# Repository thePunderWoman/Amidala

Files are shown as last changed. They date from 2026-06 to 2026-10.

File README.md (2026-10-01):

<p align="center">
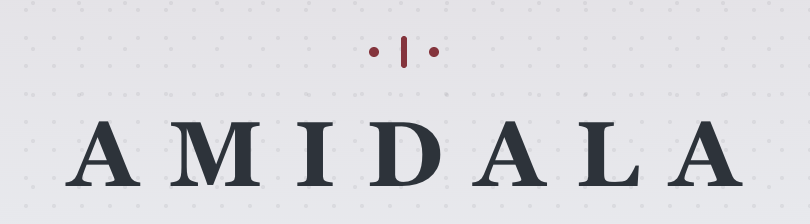
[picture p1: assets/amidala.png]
Amidala
  
</p>

<p align="center">
  <a href="https://github.com/thePunderWoman/Amidala/actions/workflows/ci.yml">
    
  </a>
  <a href="https://github.com/thePunderWoman/Amidala/releases/latest">
    
  </a>
</p>

**Amidala** is an ESP32-S3 firmware for controlling your droids. It runs on the [Amidala PCB](PCB/) — a PCB designed to make wiring a full-featured droid build straightforward — and is compatible with both the N8R2 (8 MB flash) and N16R8 (16 MB flash) module variants. Amidala is designed to pair with [Snips Controllers](https://github.com/thePunderWoman/SnipsControllers), coming soon, but can work with older Stealth controllers, bluetooth, or RC.

> **Building from source?** Flash size and PSRAM mode are baked into the firmware image at build time, so you need to tell PlatformIO which module your board has *before* your first flash — it can't be changed later via the web UI. Check the label on your ESP32-S3 module (or your PCB order) for "N8R2" or "N16R8", then build/upload with the matching environment: `pio run -e esp32s3-n16r8 -t upload` (the default) or `pio run -e esp32s3-n8r2 -t upload`. Just want to flash a droid rather than develop firmware? The **Firmware Installer** wizard below flashes a prebuilt image over USB — no toolchain needed.

> **[Amidala Wizards →](https://thepunderwoman.github.io/Amidala/)** — browser-based tools for setting up your droid. Includes a **Firmware Installer** for flashing prebuilt firmware over Web Serial, and a **Config Converter** for migrating Stealth RC / OG Amidala configs to the current format.

---

## Features

- **XBee wireless control** — secure, long-range, low-latency control via XBee 3 modules
- **Multiple Controller Support** — works with Snips Controllers (currently in prototype stage), classic stealth controllers, standard Bluetooth gamepads, and analog RC (PPM) input.
- **Wi-Fi configuration UI** — browser-based interface for fully configuring your droid without needing to pull the SD card.
- **WCB mesh networking** — join a [WCB](https://github.com/greghulette/WCBClient) ESP-NOW mesh to coordinate commands across multiple boards (e.g. a separate body controller) with no extra wiring.
- **Native HCR support** — full Human Cyborg Relations vocalizer integration, whether the HCR is wired straight to the board or owned by a WCB running its native HCR mode (Audio page → Serial Configuration).
- **Built in Serial Monitor** — full featured onboard native serial monitor to view traffic in real time, even across your WCB Mesh.
- **Advanced Dome Drive** — Built-in support for auto dome drive with a Pololu encoder motor and hall sensor, or any other basic PWM dome drive.
- **Flexible drive systems** — PWM, Sabertooth serial, or RoboteQ (PWM, serial, or hybrid)
- **Native built-in safety features** — Web based e-stop, dome obstruction motor disconnect, auto motor disable on controller disconnect.
- **Layers of controller button configurations** — with short-press, double-press, long-press, and alt-modifier layers
- **Effectively unlimited serial strings and gestures** — the only limits are your imagination!
- **Reassignable GPIO pin roles** — trade any of the board's digital output, analog input, PPM, or servo headers for another role right from the web UI (e.g. give up a digital output for a 5th servo channel), no reflashing needed
- **Reassignable dome/drive serial ports** — move the dome drive or drive system's serial link (RoboClaw, Sabertooth, RoboteQ serial) onto either of the board's two hardware UARTs from the web UI, for wiring that doesn't match the reference PCB or to free up a header for other hardware
- **And more** — I2C aux output, digital outputs, analog inputs, SD card config, servo outputs, and emergency stop handling

---

## Controller Support

Amidala is natively designed to work with [Snips Controllers](https://github.com/thePunderWoman/SnipsControllers) or other XBee-based dual handheld pocket controllers. It can also be used with standard Bluetooth controllers and RC.

## Web Configuration UI

<p align="center">
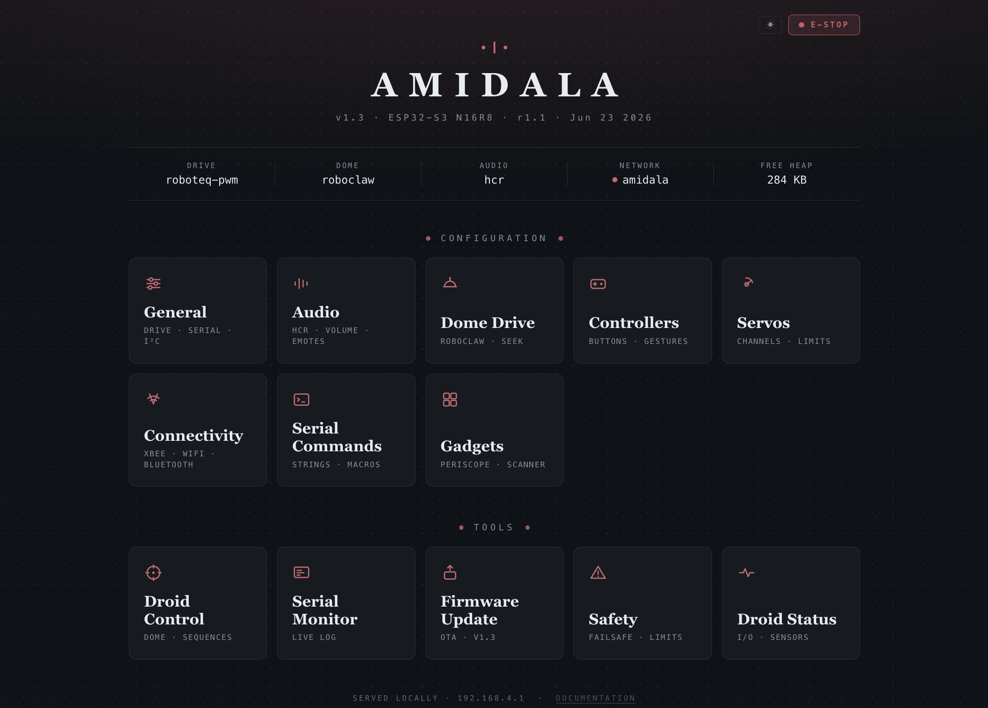
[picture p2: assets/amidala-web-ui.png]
Amidala
  
</p>

The Amidala web interface allows you total control over your droid's configuration. You can set up your controller configuration, which buttons trigger what, add serial commands, set defaults for audio, dome positioning, safety timeouts, emergency stop commands, configure Bluetooth, see digital pin statuses, use the serial monitor, configure your droid's gadgets, and even use the droid control page to trigger sequences, trigger emotes, and dome controls. See more in the wiki.

## Availability and Pricing

Amidala boards are currently available to beta testers. Please let me know if you would prefer to have it pre-soldered or bare. Either way, it will come with the headers, slots, jumper, and power terminals. The ESP32-S3-N16R8 is standard and can be sourced from your favorite location. You will also need an XBee3 module if you intend to use Snips or Stealth controllers with your build. See the Wiki page for details on the recommended options. Price is $30 per board plus shipping, which includes a small donation to charity. Note: This does __not__ include controllers. However, once Snips Controllers are past the prototype phase, we will offer them together with Amidala.

Please reach out if you are interested in helping beta test.

## Get Started

> **[Documentation Wiki →](https://github.com/thePunderWoman/Amidala/wiki)**

The wiki covers everything from first flash through full configuration. For a quick look at every available config key, see [example_config.txt](example_config.txt) — it's a complete annotated reference used on a real build. Although once you get set up initially, you won't need to look at this file again, as you can update every config option through the web UI.

---

## The Amidala PCB

<p align="center">
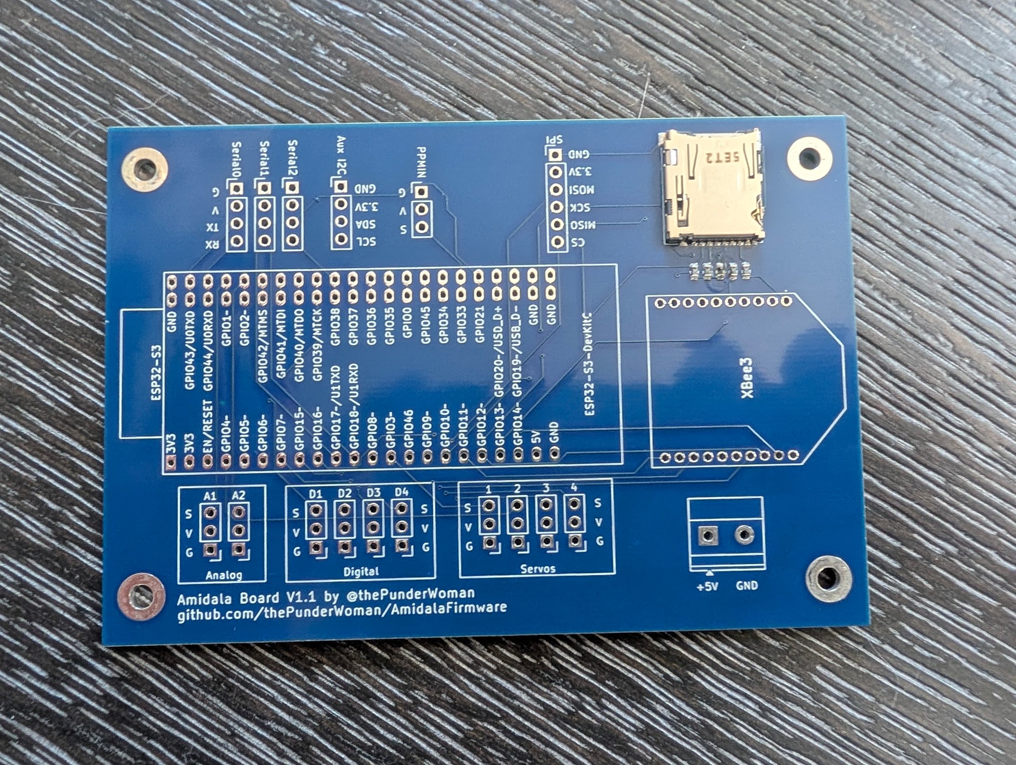
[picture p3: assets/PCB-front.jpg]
Amidala PCB front
  
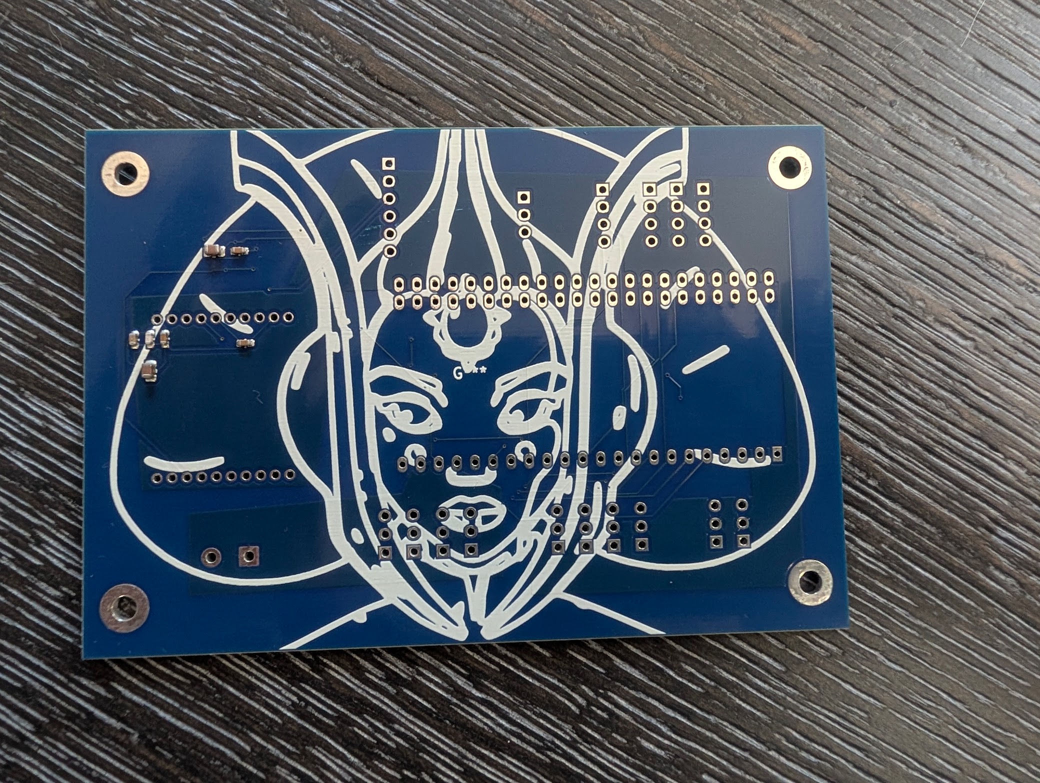
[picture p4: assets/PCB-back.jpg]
Amidala PCB back
  
</p>

The Amidala PCB is a purpose-built carrier for the ESP32-S3, designed to consolidate all the connectors a typical R2 build needs onto a single board:

- 4 servo headers (LEDC PWM)
- 4 digital output pins
- 2 analog inputs
- 3 serial headers (UART0 primary out, plus UART1 and UART2 for the dome drive and drive system's serial link — reassignable between the two, see below)
- Auxiliary I2C header
- Native XBee slot (SPI, no adapter needed)
- Micro SD card reader
- Additional SPI breakout
- PPM input for RC receivers

> The servo, digital output, analog input, and PPM header counts above are just the defaults — each of those 11 pins can be independently reassigned to a different role from the web UI's Pins page (e.g. trade a digital output for a 5th servo channel, up to the ESP32-S3's 8-channel PWM ceiling). A reboot applies the change; no reflashing or rewiring of the PCB itself is needed.
>
> Likewise, UART1 and UART2 default to the dome drive and drive system's serial link respectively (matching the reference wiring), but either can be reassigned to the other from the web UI's Serial Ports page — e.g. if your build's wiring swaps which header the RoboClaw is actually connected to. UART0 always carries the primary serial-out / WCB mesh path and isn't reassignable.

> **[PCB details, Stackup circuit design, and BOM →](PCB/)**

---

## License

This project is released under the [GNU General Public License v2](LICENSE). You are free to use, modify, and distribute it — including your own modifications — as long as you share the source code of any distributed derivatives under the same license.

---

## Contributing

Bug reports and feature requests are welcome — please use the [issue tracker](https://github.com/thePunderWoman/Amidala/issues).

If you'd like to contribute code, see [CONTRIBUTING.md](CONTRIBUTING.md).

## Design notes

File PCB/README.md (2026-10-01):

# AmidalaBoard (AmidalaShield)

A custom KiCad PCB shield designed specifically for the [Amidala Firmware](https://github.com/thePunderWoman/AmidalaFirmware) — a control system for astromech and similar droid builds. This board provides all the I/O the firmware needs in a single, purpose-built package.

**Designed by [thePunderWoman](https://github.com/thePunderWoman)**

The electrical design is written in [Stackup KDL](stackup/board.kdl), using the pinned
Stackup parts library plus [board-specific parts](stackup/parts.kdl). The
[KiCad PCB](AmidalaShield.kicad_pcb) is linked to it through `AmidalaShield.stackup_sch`;
sync it with the Stackup KiCad plugin after changing the design. See
[stackup/README.md](stackup/README.md).

---

## Overview

The AmidalaShield is a carrier/breakout board for the **ESP32-S3 N16R8 DevKit**. It breaks out and conditions the ESP32-S3's peripherals for the specific needs of the Amidala Firmware: wireless XBee communication, multi-channel servo control, RC receiver input, SD card storage, and expansion headers for additional peripherals.

---

## Requirements

- **Microcontroller:** ESP32-S3 N16R8 DevKit (16 MB flash, 8 MB PSRAM)
- **Wireless modules:** XBee3 modules (x2 recommended — one for drive controller, one for dome controller)

---

## Hardware Features

### Wireless Communication
- **XBee3 module socket** for dual-controller operation (drive + dome)

### Servo Control
- **4× PWM servo outputs** — 3-pin headers (signal, power, ground)

### Serial Ports
- **3× hardware serial ports** — UART0 (shared with USB/programming, silkscreen "Serial 0"), UART1 ("Serial 1"), and UART2 ("Serial 2"). None of these are bit-banged/software serial — the ESP32-S3's UART peripherals route through its GPIO matrix onto whichever pins are needed, unlike chips with a single hardware UART. Firmware reassigns the dome drive and drive system's serial link between Serial 1/Serial 2 at runtime — see the Amidala firmware wiki's [Serial Ports](https://github.com/thePunderWoman/Amidala/wiki/Serial-Ports) page.

### I/O
- **4× digital I/O pins**
- **2× analog input pins**
- **1× Aux I2C header** — for external I2C devices

### RC Control
- **PPM input (ppmin)** — for analog RC receiver

### Storage
- **Built-in microSD card reader** — used for `config.txt` at startup (matches Amidala Firmware config system)

### Expansion
- **Dedicated SPI header** — for external SPI peripherals

---

## Repository Contents

| File/Folder | Description |
|---|---|
| `stackup/board.kdl` | Electrical design (Stackup KDL), replacing the KiCad schematics |
| `stackup/parts.kdl` | Parts the Stackup library doesn't have (DevKitC, microSD socket, screw terminal, 3-way jumper) |
| `AmidalaShield.kicad_pcb` | PCB layout, synced from the Stackup design |
| `gerbers/` | Production-ready Gerber files |
| `libraries/` | Project-specific KiCad symbol/footprint libraries |
| `images/` | Board renders and screenshots |

---

## Getting Started

1. Clone this repo and open `AmidalaShield.kicad_pro` in KiCad 8+.
2. Review the [Stackup design](stackup/board.kdl) and the GPIO table below for pin assignments before assembling.
3. Use the Gerber files in `gerbers/` to order PCBs from your preferred fab.
4. Flash your ESP32-S3 with the [Amidala Firmware](https://github.com/thePunderWoman/AmidalaFirmware).
5. Place a `config.txt` on the microSD card — see the firmware repo for a full annotated example.

---

## GPIO Table

> **V1.1** — Updated GPIO assignments for ESP32-S3 WROOM-1 N8R2/N16R2 (Quad flash/PSRAM).
> Avoid GPIO35–37 on R8 (Octal) variants. GPIO48 reserved for onboard RGB LED.

| Function | GPIO | DevKit Side | Notes |
|---|---|---|---|
| **SPI MOSI** | GPIO11 | Left | Native FSPI, shared bus |
| **SPI MISO** | GPIO13 | Left | Native FSPI, shared bus |
| **SPI SCK** | GPIO12 | Left | Native FSPI, shared bus |
| **SD Card CS** | GPIO10 | Left | |
| **XBee CS** | GPIO7 | Left | |
| **SPI Spare CS** | GPIO14 | Left | Exposed header |
| **XBee ATTN** | GPIO16 | Left | |
| **XBee SLEEP** | GPIO15 | Left | |
| **I2C SDA** | GPIO8 | Left | Native I2C default |
| **I2C SCL** | GPIO9 | Left | Native I2C default |
| **UART0 TX** | GPIO43 | Right | Shared w/ USB — do not use simultaneously. Silkscreen "Serial 0"; fixed, carries the main serial-out/WCB mesh path |
| **UART0 RX** | GPIO44 | Right | Shared w/ USB — do not use simultaneously |
| **UART1 TX** | GPIO17 | Right | Silkscreen "Serial 1". Reassignable between the dome/drive serial link (default: dome) |
| **UART1 RX** | GPIO18 | Right | |
| **UART2 TX** | GPIO21 | Right | Silkscreen "Serial 2". Real hardware UART, not software serial. Reassignable between the dome/drive serial link (default: drive) |
| **UART2 RX** | GPIO38 | Right | |
| **PPMIN** | GPIO47 | Right | |
| **Analog 1** | GPIO1 | Right | ADC1_0, WiFi-safe |
| **Analog 2** | GPIO2 | Right | ADC1_1, WiFi-safe |
| **Servo 1** | GPIO3 | Left | Strapping pin (JTAG source), safe after boot |
| **Servo 2** | GPIO4 | Left | |
| **Servo 3** | GPIO5 | Left | |
| **Servo 4** | GPIO6 | Left | |
| **Digital 1** | GPIO39 | Right | Goes HIGH after reset (not LOW like most GPIOs) |
| **Digital 2** | GPIO40 | Right | |
| **Digital 3** | GPIO41 | Right | |
| **Digital 4** | GPIO42 | Right | Transitions low on reset slightly slower |
| **RGB LED** | GPIO48 | Right | Reserved — onboard DevKit RGB LED |
| **NC** | GPIO8 | Left | Reserved |

### Pins Intentionally Avoided

| GPIO | Reason |
|---|---|
| GPIO0 | Strapping pin — boot mode |
| GPIO3 | Strapping pin — JTAG source (used for Servo 1, safe after boot) |
| GPIO19/20 | USB D-/D+ |
| GPIO26–32 | Internal SPI flash/PSRAM — never use |
| GPIO35–37 | Internal on Octal (R8) variants — safe on R2 only |
| GPIO45 | Strapping pin — VDD_SPI voltage |
| GPIO46 | Strapping pin |

---

## License

This hardware design is licensed under the [Creative Commons Attribution-NonCommercial-ShareAlike 4.0 International License](LICENSE.md) (CC BY-NC-SA 4.0).

You are free to share and adapt this design for non-commercial purposes, as long as you give appropriate credit and distribute any adaptations under the same license.

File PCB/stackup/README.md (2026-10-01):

# Amidala Shield Stackup design

`board.kdl` is the shield's electrical design. It imports parts from the
[Stackup library](https://github.com/stackup-eda/library) pinned in the repository's
`manifest.kdl`. `parts.kdl` defines the parts the library doesn't have: the ESP32-S3-DevKitC-1,
the Hirose microSD socket, the 5 V screw terminal and the 3-way supply jumper.

The design was ported 1:1 from the KiCad schematics. Designators and net names are unchanged, so
the existing routing in `../AmidalaShield.kicad_pcb` carried over as-is.

From the repository root:

```sh
stackup check PCB/stackup/board.kdl --locked     # check the design
```

To update the PCB after changing the design, use **Sync PCB from stackup** in KiCad's PCB editor
(the board is linked by `PCB/AmidalaShield.stackup_sch`), or sync it headless with the board
closed:

```sh
/Applications/KiCad/KiCad.app/Contents/Frameworks/Python.framework/Versions/Current/bin/python3 \
  <stackup checkout>/kicad-plugin/sync_headless.py PCB/AmidalaShield.kicad_pcb
```

Commit the synced PCB together with the KDL change. CI checks the design with the Cargo-locked CLI
in `ci/stackup/` and fails if syncing would change the committed PCB. Each footprint records the
`board.kdl` line it came from, so even a change that only moves lines needs a resync.

Install the same CLI version CI uses with `cargo install stackup-eda --version 0.2.0 --locked`, and
the KiCad plugin from a checkout of [stackup-eda/stackup](https://github.com/stackup-eda/stackup)
at `v0.2.0` with `python3 kicad-plugin/install.py`.

## Known gaps carried over from the schematics

- **No MPNs.** The original schematics didn't specify purchasing details, so `stackup bom` reports
  every part as missing an MPN.
- **XBee3 SPI_ATTN has no pull-up.** `stackup check` reports a note that the strap's rest level
  can't be checked. The fix is a resistor in the next board revision (issue #185).

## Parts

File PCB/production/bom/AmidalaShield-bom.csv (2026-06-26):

Id | Designator | Footprint | Quantity | Designation | Supplier and ref
1 | R3,R1,R2,R5 | R_0603_1608Metric | 4 | 10k
2 | C4,C7 | C_0805_2012Metric | 2 | 10u
3 | C2,C1,C3 | C_0603_1608Metric | 3 | 100n
4 | C9 | CP_EIA-3216-18_Kemet-A | 1 | 100µF
5 | J3 | microSD_HC_Hirose_DM3AT-SF-PEJM5 | 1 | Micro_SD_Card
6 | C6 | C_0603_1608Metric | 1 | 8.2p
7 | C5 | C_0603_1608Metric | 1 | 1u

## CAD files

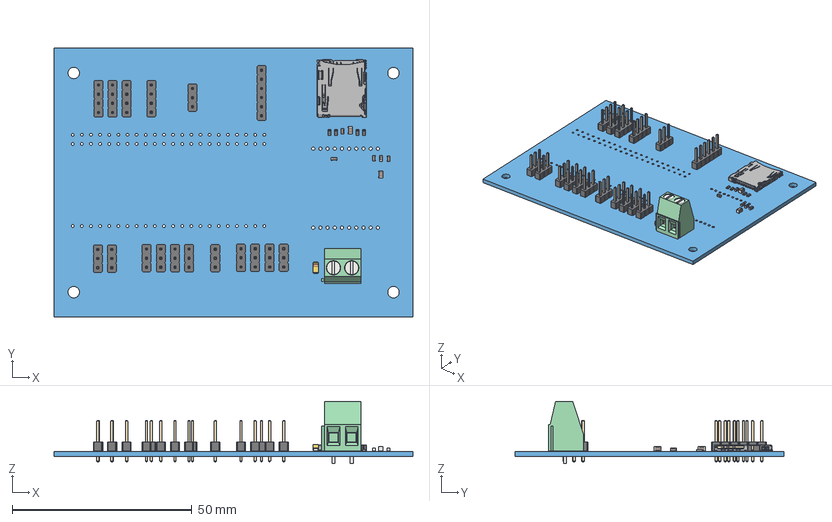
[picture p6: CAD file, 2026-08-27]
PCB/AmidalaShield.step
99.9 x 74.9 x 17.3 mm
R_0603_1608Metric x 4
PinHeader_1x04_P2.54mm_Vertical x 4
C_0805_2012Metric x 2
C_0603_1608Metric x 5
PinHeader_1x03_P2.54mm_Vertical x 12
TerminalBlock_Phoenix_MKDS-1,5-2-5.08_1x02_P5.08mm_Horizontal
CP_EIA-3216-18_Kemet-A
PinHeader_1x06_P2.54mm_Vertical
microSD_HC_Hirose_DM3AT-SF-PEJM5
AmidalaShield_PCB

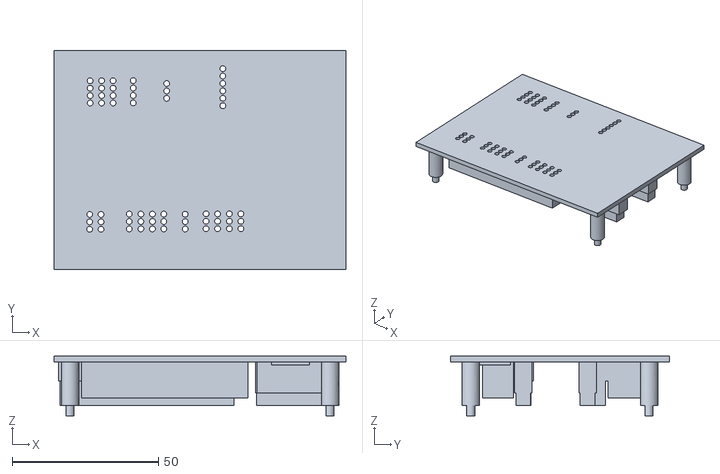
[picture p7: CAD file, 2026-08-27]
PCB/amidala solder jig.stl
99.9 x 74.9 x 20.5

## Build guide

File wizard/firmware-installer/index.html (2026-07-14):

# Amidala Firmware Installer

Build a firmware image for your exact hardware and flash it over USB — no toolchain required.

Checking latest release…

1

Select Hardware

2

Connect & Flash

3

Done

## Tell us about your build

These are compile-time hardware choices — pick the ones that match your droid. Everything else (WiFi, audio, buttons, gestures) is configured later through the web UI.

ESP32-S3 module

Check the label on your ESP32-S3 module (or your PCB order) for "N8R2" or "N16R8" — this can't be changed later without reflashing.

Drive system

Whichever motor controller drives your legs.

Dome drive

Whichever motor controller spins your dome.

Continue →

## Enter bootloader mode

The ESP32-S3's USB port has no auto-reset circuitry, so you'll need to put it into bootloader mode by hand before connecting:

1. Plug the board in over USB, if it isn't already.
2. Hold the BOOT button.
3. Tap and release RESET (while still holding BOOT).
4. Release BOOT.
5. Click Connect below and select the board's serial port.

⚠ Before you flash This installs fresh firmware and erases all saved settings on the board (WiFi credentials, config, calibration) — this is meant for first-time setup or a full reset, not an incremental update. Do not disconnect the board once flashing starts.

Connect Flash Firmware

Preparing…

0%

Log

← Back

✓ Flash complete — your board is rebooting into the new firmware.

## Next steps

Once the board reboots, it broadcasts its own WiFi access point — connect to it and open the web UI to finish setup (WiFi, audio, buttons, gestures, and more).

Migrating an existing Stealth RC or OG Amidala config? Use the Config Converter to bring your old settings forward.

Flash Another Board

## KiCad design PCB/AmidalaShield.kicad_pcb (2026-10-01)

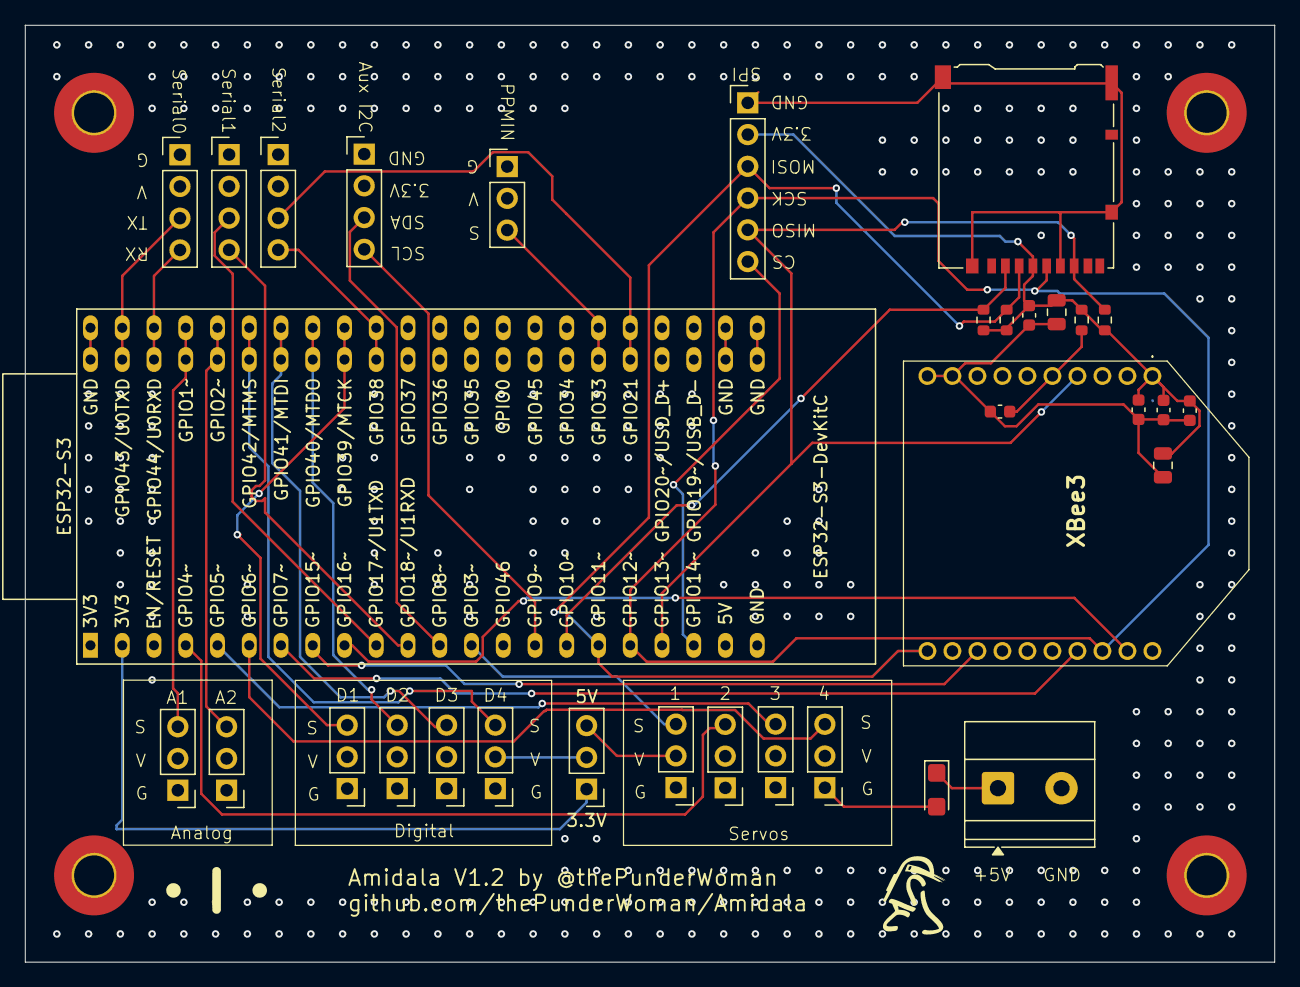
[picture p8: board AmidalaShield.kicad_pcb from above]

Board: 4 copper layers, 99.9 x 74.9 mm, 33 parts (0 on the bottom side), 32 nets.

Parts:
C1, C2, C3: 100nF; C_0603_1608Metric
C4, C7: 10µF; C_0805_2012Metric
C5: 1µF; C_0603_1608Metric
C6: 8.2pF; C_0603_1608Metric
C9: 100µF; CP_EIA-3216-18_Kemet-A
ESP32-S3: ESP32-S3-DevKitC; ESP32-S2-DevKitC-1
I2C1: Aux I2C; PinHeader_1x04_P2.54mm_Vertical
J1: Screw_Terminal_01x02; TerminalBlock_Phoenix_MKDS-1,5-2-5.08_1x02_P5.08mm_Horizont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
J3: Micro_SD_Card; microSD_HC_Hirose_DM3AT-SF-PEJM5
JP1: Jumper_3_Open; PinHeader_1x03_P2.54mm_Vertical
J_Analog1: A1; PinHeader_1x03_P2.54mm_Vertical
J_Analog2: A2; PinHeader_1x03_P2.54mm_Vertical
J_Digital1: D1; PinHeader_1x03_P2.54mm_Vertical
J_Digital2: D2; PinHeader_1x03_P2.54mm_Vertical
J_Digital3: D3; PinHeader_1x03_P2.54mm_Vertical
J_Digital4: D4; PinHeader_1x03_P2.54mm_Vertical
J_PPMIN1: PPMIN; PinHeader_1x03_P2.54mm_Vertical
J_Servo1: 1; PinHeader_1x03_P2.54mm_Vertical
J_Servo2: 2; PinHeader_1x03_P2.54mm_Vertical
J_Servo3: 3; PinHeader_1x03_P2.54mm_Vertical
J_Servo4: 4; PinHeader_1x03_P2.54mm_Vertical
R1, R2, R3, R5: 10kΩ; R_0603_1608Metric
SPI1: SPI; PinHeader_1x06_P2.54mm_Vertical
SWSerial1: Serial2; PinHeader_1x04_P2.54mm_Vertical
Serial0: Serial0; PinHeader_1x04_P2.54mm_Vertical
Serial1: Serial1; PinHeader_1x04_P2.54mm_Vertical
XBee3: XB3-24Z8UT-J; XB324Z8UTJ

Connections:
+3.3V: C2.1, C3.1, C4.1, C5.1, C6.1, C7.1, ESP32-S3.1 (3V3), ESP32-S3.2 (3V3), I2C1.2, J3.4 (VDD), JP1.1 (A), J_PPMIN1.2, R1.1, R2.1, R3.1, R5.1, SPI1.2, SWSerial1.2, Serial0.2, Serial1.2, XBee3.1 (VCC)
+5V: C9.1, ESP32-S3.21 (5V), J1.1, JP1.3 (B), J_Servo1.2, J_Servo2.2, J_Servo3.2, J_Servo4.2
/Comms/GPIO8: ESP32-S3.12 (GPIO8/ADC1_CH7), I2C1.3
/Comms/GPIO9: ESP32-S3.15 (GPIO9/ADC1_CH8), I2C1.4
/Comms/GPIO17: ESP32-S3.10 (GPIO17/ADC2_CH6), Serial1.3
/Comms/GPIO18: ESP32-S3.11 (GPIO18/ADC2_CH7), Serial1.4
/Comms/GPIO21: ESP32-S3.27 (GPIO21), SWSerial1.3
/Comms/GPIO38: ESP32-S3.35 (GPIO38), SWSerial1.4
/Comms/GPIO43: ESP32-S3.43 (GPIO43/U0TXD), Serial0.3
/Comms/GPIO44: ESP32-S3.42 (GPIO44/U0RXD), Serial0.4
/Pins/GPIO1: ESP32-S3.41 (GPIO1/ADC1_CH0), J_Analog1.3
/Pins/GPIO2: ESP32-S3.40 (GPIO2/ADC1_CH1), J_Analog2.3
/Pins/GPIO39: ESP32-S3.36 (GPIO39/MTCK), J_Digital1.3
/Pins/GPIO40: ESP32-S3.37 (GPIO40/MTDO), J_Digital2.3
/Pins/GPIO41: ESP32-S3.38 (GPIO41/MTDI), J_Digital3.3
/Pins/GPIO42: ESP32-S3.39 (GPIO42/MTMS), J_Digital4.3
/RC Control/GPIO47: ESP32-S3.28 (GPIO47), J_PPMIN1.3
/SPI/GPIO7: ESP32-S3.7 (GPIO7/ADC1_CH6), XBee3.17 (AD3/DIO3/SPI_~SSEL)
/SPI/GPIO10: ESP32-S3.16 (GPIO10/ADC1_CH9), J3.2 (DAT3/CD), R2.2
/SPI/GPIO11: ESP32-S3.17 (GPIO11/ADC2_CH0), J3.3 (CMD), R3.2, SPI1.3, XBee3.11 (DIO4/SPI_MOSI)
/SPI/GPIO12: ESP32-S3.18 (GPIO12/ADC2_CH1), J3.5 (CLK), SPI1.4, XBee3.18 (AD2/DIO2/SPI_CLK)
/SPI/GPIO13: ESP32-S3.19 (GPIO13/ADC2_CH2), J3.7 (DAT0), R5.2, SPI1.5, XBee3.4 (DIO12/SPI_MISO)
/SPI/GPIO14: ESP32-S3.20 (GPIO14/ADC2_CH3), SPI1.6
/SPI/GPIO15: ESP32-S3.8 (GPIO15/ADC2_CH4/32K_P), XBee3.13 (ON/~SLEEP/DIO9)
/SPI/GPIO16: ESP32-S3.9 (GPIO16/ADC2_CH5/32K_N), XBee3.19 (AD1/DIO1/SPI_~ATTN)
/Servos/GPIO3: ESP32-S3.13 (GPIO3/ADC1_CH2), J_Servo1.3
/Servos/GPIO4: ESP32-S3.4 (GPIO4/ADC1_CH3), J_Servo2.3
/Servos/GPIO5: ESP32-S3.5 (GPIO5/ADC1_CH4), J_Servo3.3
/Servos/GPIO6: ESP32-S3.6 (GPIO6/ADC1_CH5), J_Servo4.3
GND: C1.2, C2.2, C3.2, C4.2, C5.2, C6.2, C7.2, C9.2, ESP32-S3.22 (GND), ESP32-S3.23 (GND), ESP32-S3.24 (GND), ESP32-S3.44 (GND), I2C1.1, J1.2, J3.6 (VSS), J3.11 (SHIELD), J_Analog1.1, J_Analog2.1, J_Digital1.1, J_Digital2.1, J_Digital3.1, J_Digital4.1, J_PPMIN1.1, J_Servo1.1, J_Servo2.1, J_Servo3.1, J_Servo4.1, SPI1.1, SWSerial1.1, Serial0.1, Serial1.1, XBee3.9 (~DTR/SLEEP_RQ/DIO8), XBee3.10 (GND)
unnamed: C1.1, R1.2, XBee3.5 (~RESET)
VCC_DIG: JP1.2 (C), J_Analog1.2, J_Analog2.2, J_Digital1.2, J_Digital2.2, J_Digital3.2, J_Digital4.2

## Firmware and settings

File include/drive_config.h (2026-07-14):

// drive_config.h
// Drive and dome system configuration for Amidala Firmware.
//
// Edit the two "Active selection" lines to switch hardware configurations.
// Everything below the "Drive system resolution" comment is derived
// automatically — do not edit those lines.

#pragma once

// ---- Drive system type constants --------------------------------------------

#define DRIVE_SYSTEM_PWM                1
#define DRIVE_SYSTEM_SABER              2
#define DRIVE_SYSTEM_ROBOTEQ_PWM        3
#define DRIVE_SYSTEM_ROBOTEQ_SERIAL     4
#define DRIVE_SYSTEM_ROBOTEQ_PWM_SERIAL 5

// Active selection (uncomment the one in use). Guarded by #ifndef so a build
// can also override it via `-D DRIVE_SYSTEM=<n>` (used by the firmware
// installer wizard's CI matrix build) without editing this file.
// #define DRIVE_SYSTEM DRIVE_SYSTEM_ROBOTEQ_PWM_SERIAL
#ifndef DRIVE_SYSTEM
#define DRIVE_SYSTEM DRIVE_SYSTEM_ROBOTEQ_PWM
#endif

// ---- Dome drive type constants -----------------------------------------------

#define DOME_DRIVE_SABER    2
#define DOME_DRIVE_PWM      3
#define DOME_DRIVE_ROBOCLAW 4

// Active selection (uncomment the one in use). Guarded by #ifndef so a build
// can also override it via `-D DOME_DRIVE=<n>` (used by the firmware
// installer wizard's CI matrix build) without editing this file.
// #define DOME_DRIVE DOME_DRIVE_PWM
// #define DOME_DRIVE DOME_DRIVE_SABER
#ifndef DOME_DRIVE
#define DOME_DRIVE DOME_DRIVE_ROBOCLAW
#endif

// ---- Speed and acceleration parameters --------------------------------------

#define MAXIMUM_SPEED       1.0f  // percentage 0.0 - 1.0. default 50%
#define MAXIMUM_GUEST_SPEED 0.5f  // percentage 0.0 - 1.0. default 30%
#define DOME_MAXIMUM_SPEED  1.0f  // percentage 0.0 - 1.0. default 100%

// Scale value of 1 means instant. Scale value of 100 means that the throttle
// will increase 1/100 every 25ms
#define ACCELERATION_SCALE 100
// Scale value of 1 means instant. Scale value of 20 means that the throttle
// will decrease 1/20 every 25ms
#define DECELRATION_SCALE  20

// Set to true if acceleration/deceleration should be applied
#define SCALING false

// ---- Dome motion defaults ---------------------------------------------------

#define DEFAULT_DOME_HOME_POSITION      50
#define DEFAULT_DOME_ACCELERATION_SCALE 20
#define DEFAULT_DOME_DECELERATION_SCALE 50
#define DEFAULT_DOME_SEEK_MIN_DELAY     6
#define DEFAULT_DOME_SEEK_MAX_DELAY     8
#define DEFAULT_DOME_TARGET_MIN_DELAY   0
#define DEFAULT_DOME_TARGET_MAX_DELAY   1
#define DEFAULT_DOME_SEEK_LEFT          80
#define DEFAULT_DOME_SEEK_RIGHT         80
#define DEFAULT_DOME_FUDGE              10
#define DEFAULT_DOME_SPEED_HOME         40
#define DEFAULT_DOME_SPEED_SEEK         60
#define DEFAULT_DOME_SPEED_TARGET       100
#define DEFAULT_DOME_SPEED_MIN          5
#define DEFAULT_DOME_DECEL_ZONE         30
#define DEFAULT_DOME_TIMEOUT            5
#define DEFAULT_DOME_INVERTED           true
#define DEFAULT_DOME_MIN_PULSE          1000
#define DEFAULT_DOME_MAX_PULSE          2000

// ---- RoboClaw dome drive defaults -------------------------------------------
// These apply only when DOME_DRIVE == DOME_DRIVE_ROBOCLAW.

// Serial port used by the RoboClaw.
// UART1 (GPIO17/18) — Serial0 (UART0) carries the WCB downstream output.
// DOME_DRIVE_SERIAL is intentionally NOT defined here so pin_config.h still
// assigns SERIAL = Serial0 for the primary output.
#if DOME_DRIVE == DOME_DRIVE_ROBOCLAW
#define ROBOCLAW_SERIAL    Serial1   // UART1, GPIO17/18
#define ROBOCLAW_RX_PIN    18        // UART1 RX
#define ROBOCLAW_TX_PIN    17        // UART1 TX
#define ROBOCLAW_BAUD_RATE 38400
#endif

// Default RoboClaw hardware settings
#define DEFAULT_DOME_ROBOCLAW_ADDRESS 128  // packet-serial default address (0x80)
#define DEFAULT_DOME_ROBOCLAW_CHANNEL 1    // motor channel: 1 = M1, 2 = M2

// Encoder counts per motor shaft revolution (CPR).
// For the Pololu motor in this build the CPR is 1200.
// Change this constant if a different motor is swapped in; it is not a
// runtime config key because it is a hardware property of the motor itself.
#define DOME_MOTOR_CPR 1200

// Max encoder pulses per second sent to RoboClaw SpeedM1/M2.
// Tune this to the motor's realistic no-load maximum before applying load.
#define DEFAULT_DOME_ROBOCLAW_QPPS 800

// Milliseconds of zero encoder movement while the motor is commanded before
// the system declares an obstruction and stops.
#define DEFAULT_DOME_STALL_TIMEOUT_MS 500

// Milliseconds allowed for the homing sweep to find the hall sensor.
// If it expires the system falls back to manual mode with a console warning.
#define DEFAULT_DOME_HOMING_TIMEOUT_MS 15000

// Speed (fraction of QPPS) used during automatic homing and calibration.
// Keep these low enough to be safe on first power-on.
#define DEFAULT_DOME_HOMING_SPEED   0.20f  // 20 % of QPPS
#define DEFAULT_DOME_CALIBRATE_SPEED 0.30f // 30 % of QPPS

// Hardware debounce window for the hall-effect sensor interrupt (ms).
// Triggers arriving faster than this are ignored.
#define DEFAULT_DOME_HALL_DEBOUNCE_MS 50

// Number of complete dome revolutions averaged during calibration.
#define DOME_CALIBRATION_ROTATIONS 10

// Sequence-pause watchdog (dome=seqon[,<seconds>]).  If no dome=seqoff arrives
// within the pause window, the pause auto-clears so the dome resumes its
// normal auto-behaviors even if the body/dome controller crashes mid-sequence.
#define DEFAULT_DOME_SEQUENCE_PAUSE_MS 30000   // 30s default when no arg given
#define DOME_SEQUENCE_PAUSE_MAX_MS     300000  // 5 min safety cap

// EEPROM layout for RoboClaw calibration data.
// Stored at a fixed offset well past the existing SC23 XBee block (0x64)
// and servo block (0xEA) to avoid collisions.
//
//   Offset  Size  Contents
//   0x200   4     Signature bytes: 'R','C','0','1'
//   0x204   4     int32_t  ticksPerDomeRev  (0 → not yet calibrated)
//
// Reading: if the 4-byte signature matches, load ticksPerDomeRev.
// Writing: always write both signature and data atomically.
#define DOME_ROBOCLAW_EEPROM_ADDR 0x200
#define DOME_ROBOCLAW_EEPROM_SIG0 'R'
#define DOME_ROBOCLAW_EEPROM_SIG1 'C'
#define DOME_ROBOCLAW_EEPROM_SIG2 '0'
#define DOME_ROBOCLAW_EEPROM_SIG3 '1'

// ---- Drive system resolution (derived — do not edit) ------------------------

// Drive/dome serial links use AUX_SERIAL (UART2, GPIO21/38 — see
// pin_config.h) rather than Serial0, which is reserved for the WCB
// downstream output.
#if DRIVE_SYSTEM == DRIVE_SYSTEM_SABER
#define DRIVE_SERIAL      AUX_SERIAL
#define DRIVE_BAUD_RATE   9600      // Sabertooth packet-serial default
// Do NOT also define DOME_DRIVE_SERIAL here: AmidalaFirmware.ino's
// Serial0.begin() already prefers DRIVE_SERIAL over DOME_DRIVE_SERIAL, so
// this was never needed for that call — and defining it unconditionally
// (regardless of DOME_DRIVE) leaked into pin_config.h's
// `#if !defined(DOME_DRIVE_SERIAL)` guard, silently disabling the SERIAL
// macro (WCB downstream output) for any Sabertooth-drive build with a
// non-Sabertooth dome. The block below already sets DOME_DRIVE_SERIAL
// correctly when the dome itself is Sabertooth.
#define CHANNEL_MIXING    true  // premix channels before sending commands
#elif DRIVE_SYSTEM == DRIVE_SYSTEM_PWM
#define CHANNEL_MIXING    false // motor controller will mix the channels
#elif DRIVE_SYSTEM == DRIVE_SYSTEM_ROBOTEQ_PWM
#define CHANNEL_MIXING    false // motor controller will mix the channels
#elif DRIVE_SYSTEM == DRIVE_SYSTEM_ROBOTEQ_SERIAL
#define DRIVE_SERIAL      AUX_SERIAL
#define DRIVE_BAUD_RATE   115200
#define CHANNEL_MIXING    false // motor controller will mix the channels
#elif DRIVE_SYSTEM == DRIVE_SYSTEM_ROBOTEQ_PWM_SERIAL
#define DRIVE_SERIAL      AUX_SERIAL
#define DRIVE_BAUD_RATE   115200
#define CHANNEL_MIXING    false // motor controller will mix the channels
#else
#error Unsupported DRIVE_SYSTEM
#endif

// #define EXPERIMENTAL_JEVOIS_STEERING

#if !defined(DRIVE_BAUD_RATE) && DOME_DRIVE == DOME_DRIVE_SABER
#define DRIVE_BAUD_RATE 9600
#endif

#if !defined(DOME_DRIVE_SERIAL) && DOME_DRIVE == DOME_DRIVE_SABER
#define DOME_DRIVE_SERIAL AUX_SERIAL
#endif

#if defined(DOME_DRIVE) && DOME_DRIVE != DOME_DRIVE_SABER && \
    DOME_DRIVE != DOME_DRIVE_PWM && DOME_DRIVE != DOME_DRIVE_ROBOCLAW
#error Unsupported DOME_DRIVE
#endif

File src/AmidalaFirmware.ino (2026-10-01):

// AmidalaFirmware.ino — entry point.
// Hardware globals live in src/globals.cpp.
// Controller logic lives in src/controller.cpp.

#include "debug.h"
#include "drive_config.h"
#include "controller.h"
#include <esp_ota_ops.h>
#include <esp_heap_caps.h>

AmidalaController amidala;

void setup() {
  // Internal DRAM is scarce (WiFi's own DMA buffers alone use ~50KB of the
  // ~140KB available), while PSRAM sits almost entirely unused by default --
  // the stock threshold below which malloc()/new always stay internal is
  // 4096 bytes, so most of WebServer/mDNS/lwIP's smaller allocations never
  // get a chance at PSRAM. Lower it so they do, freeing internal DRAM for
  // WiFi's own buffers (which can't be moved -- they require DMA-capable
  // memory) and the per-connection state it needs when a client joins.
  heap_caps_malloc_extmem_enable(64);

  esp_ota_mark_app_valid_cancel_rollback();

  REELTWO_READY();

  // Intentionally the compiled-in default, not a params.pinRole-derived
  // pin (issue #133) -- this runs before config.txt is even loaded, and
  // entropy quality doesn't depend on which ADC1 pin is sampled.
  randomSeed(analogRead(ANALOG1_PIN));

  // Drive all SPI CS pins HIGH before touching the bus so no slave sees a
  // spurious chip-select during initialisation.  GPIOs boot as floating
  // inputs; without this, SD_CS can sit LOW long enough to confuse the card.
  pinMode(SD_CS_PIN, OUTPUT);
  digitalWrite(SD_CS_PIN, HIGH);
  pinMode(XBEE_CS_PIN, OUTPUT);
  digitalWrite(XBEE_CS_PIN, HIGH);
  // XBEE_ATTN_PIN is deliberately left unconfigured (floating input) here.
  // #186 added pinMode(XBEE_ATTN_PIN, INPUT_PULLUP), reasoning that it was
  // a safe no-op if the line was actually driven -- on real hardware it
  // wasn't: it reproducibly prevented the XBee3 from ever asserting ATTN on
  // a true cold power-on (fixed only by a reset that didn't touch XBee
  // power), while a plain reset always worked. Root cause not fully
  // understood -- possibly interacting with a bootstrap/config sampling
  // window on the module's own DIO1/AD1 pin -- but confirmed via a clean
  // A/B test on hardware (issue #185). Do not re-add without new hardware
  // evidence that it's actually safe.
  pinMode(SPI_SPARE_CS_PIN, OUTPUT);
  digitalWrite(SPI_SPARE_CS_PIN, HIGH);

  // MISO is open-drain on most SD cards; pull it up so the line isn't
  // floating when no device is actively driving it. Must happen BEFORE
  // SPI.begin() claims the pin -- arduino-esp32 3.x's peripheral manager
  // deinitializes a pin's existing peripheral claim (e.g. SPI_MASTER_MISO)
  // whenever pinMode() reassigns it to plain GPIO, silently disconnecting
  // MISO from the SPI controller's receive line if this runs afterward.
  pinMode(SPI_MISO_PIN, INPUT_PULLUP);
  SPI.begin(SPI_SCK_PIN, SPI_MISO_PIN, SPI_MOSI_PIN, -1);

  // Settle time before the XBee3 sees any SPI traffic (issue #185's cold-boot
  // report: pocket remotes intermittently never connect on power-up, but any
  // reset that doesn't remove power from the XBee -- UI or the board's reset
  // button -- fixes it immediately). The XBee3's ~RESET pin has no GPIO
  // driving it, only a passive R1/C1 RC network (10k/100nF -- see
  // PCB/stackup/board.kdl), giving a ~1.2ms release delay. The ESP32
  // reaches this point in setup() well inside that same order of magnitude, so on a true cold
  // power-on both chips can be racing out of reset together, and this side
  // starts driving CS/SPI before the XBee3's own oscillator/boot sequence
  // (which needs meaningfully longer than 1.2ms) has actually finished. A
  // reset-only restart never hits this: the XBee's power, and therefore its
  // already-settled oscillator, was never interrupted.
  // 200ms is a conservative starting margin, not a spec'd number -- there's
  // no GPIO feedback from the module to know precisely when it's ready, and
  // this hasn't been confirmed against Digi's own hardware reference. Safe
  // to tune down later if field testing shows it's more than needed; it's a
  // one-time boot cost either way.
  delay(200);

  CONSOLE_SERIAL.begin(DEFAULT_BAUD_RATE);
  // Wait up to 3 s for USB-CDC to connect so boot log messages (including SD
  // init warnings) are visible on the monitor before SD.begin() is called.
  { uint32_t t = millis(); while (!CONSOLE_SERIAL && millis() - t < 3000) delay(10); }

// HALL_SENSOR_TEST (include/debug.h) is handled in AmidalaController::setup()
// (src/controller.cpp), once config.txt has been loaded -- it has to watch the
// pin the user assigned Hall to, which isn't known yet at this point.

  // XBee serial init omitted — XBee 3 uses SPI (see PR esp32-2).
#ifdef VMUSIC_SERIAL
  VMUSIC_SERIAL.begin(9600);
#endif
  // DRIVE_SERIAL/DOME_DRIVE_SERIAL (AUX_SERIAL) and ROBOCLAW_SERIAL are no
  // longer opened here (issue #147) -- both are now begin()'d in
  // AmidalaController::setup() (src/controller.cpp), at the point where
  // fTankDrive/fDomeDrive are constructed, since that's the earliest point
  // config has loaded and (eventually) the port each subsystem uses becomes
  // a runtime choice rather than a fixed macro. RDH_SERIAL shares Serial0's
  // own pins by design (see pin_config.h) and is unrelated to that work, so
  // it keeps its own early begin() here; the previous plain "SERIAL" fallback
  // branch is dropped as redundant with controller.cpp's later
  // SERIAL.begin(params.serialbaud, ...) call, which fires at the correct,
  // config-loaded baud rather than this hardcoded 115200.
#ifdef RDH_SERIAL
  RDH_SERIAL.begin(RDH_BAUD_RATE, SERIAL_8N1, SERIAL0_RX_PIN, SERIAL0_TX_PIN);
#endif

  // ESP32 EEPROM emulation requires an explicit begin() before any read/write.
  // Size covers highest used offset: DOME_ROBOCLAW_EEPROM_ADDR (0x200) + 8 bytes.
  EEPROM.begin(1024);

  SetupEvent::ready();
}

void loop() { AnimatedEvent::process(); }

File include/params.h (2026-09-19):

// params.h
// Runtime configuration struct for Amidala Firmware.
//
// AmidalaParameters holds all tunable settings (servo channels, sound banks,
// button actions, dome parameters, XBee addresses, …).  On first access
// init() zeroes the struct, applies compiled-in defaults, then overlays any
// values persisted in EEPROM.
//
// Depends on: EEPROM (Arduino <EEPROM.h> / arduino_mock.h),
//             button_actions.h (ButtonAction, GestureAction, SerialString),
//             core.h           (Gesture),
//             drive_config.h   (DEFAULT_DOME_* / DOME_MAXIMUM_SPEED, DOME_DRIVE),
//             button_actions.h (HAPPY, EMOTE_MODERATE fallback constants),
//             pin_assignment.h (PinRoleType, kMaxServoChannels)
//             <math.h>         (ceil)

#pragma once

// AmidalaParameters::init() reads the global EEPROM object, so include it here
// rather than relying on whichever header happened to pull params.h in having
// already done so -- that only held by accident (e.g. dome_drive_roboclaw.h
// brings it in early, the PWM/Saber dome drives don't), and broke the
// non-roboclaw builds once an earlier include reached params.h first. Arduino.h
// goes first for the same reason wcb_client_controller.h documents: it defines
// the min/max macros core.h relies on. Native tests get EEPROM from
// arduino_mock.h instead.
#ifdef ARDUINO
#include <Arduino.h>
#include <EEPROM.h>
#endif

#include "core.h"
#include "drive_config.h"
#include "button_actions.h"
#include "pin_assignment.h"
#include "serial_assignment.h"

// ---- Audio hardware selection -----------------------------------------------

#ifndef AUDIO_HW_HCR
#define AUDIO_HW_HCR    1  // Human Cyborg Relations board (default)
#define AUDIO_HW_VMUSIC 2  // VMusic2
#endif

// ---- Controller type selection (issue #203) ---------------------------------
// Purely a persisted "what do I have" declaration for the web UI (which nav
// cards/help banners to show, how to label the button-config page) -- it does
// NOT gate dispatch. XBee, RC, and Bluetooth input all remain capability-driven
// exactly as before (whichever hardware is actually talking gets to fire
// buttons), matching the existing graceful multi-source design.
//
// Exception (issue #204): Snips Controllers share the XBee pocket remote's
// SPI link but speak a different payload format, so controller.cpp's
// animate() DOES gate on controllertype==CONTROLLER_TYPE_SNIPS to pick which
// parser to run over that one link -- there's no other way to know which
// format is arriving. See src/xbee_spi.cpp's xbeeSPIReceiveAll() (XBee
// pocket remote) vs. xbeeSPIReceiveAllSnips() (Snips).
#define CONTROLLER_TYPE_XBEE      0  // XBee Pocket Remote (default)
#define CONTROLLER_TYPE_SNIPS     1  // Snips Controllers
#define CONTROLLER_TYPE_BLUETOOTH 2  // Bluetooth gamepad
#define CONTROLLER_TYPE_RC        3  // RC (PPM) radio

// ---- Button action storage (issue #204) -------------------------------------
// Sized for Snips Controllers' 24 buttons (12 per physical controller: 6
// macros + bumper + stick click + 4 stateful up/down buttons, x2
// controllers) -- more than the XBee pocket remote/Bluetooth gamepad's 9
// (5 drive + 4 dome). Safe to share one set of arrays across controller
// types because only one type is ever active at runtime: a saved
// "button 7" means dome-stick "cross" under CONTROLLER_TYPE_XBEE/BLUETOOTH,
// but Snips right-controller "Bumper" under CONTROLLER_TYPE_SNIPS. See the
// altbtn/mutebutton comment below for both numbering schemes.
#define MAX_BUTTONS 24

// ---- Auxiliary string count -------------------------------------------------

// ---- Default pin-role mapping (issue #133) ----------------------------------
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

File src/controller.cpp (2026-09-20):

#include "controller.h"
#include "debug.h"
#include "dome_position_math.h"
#include "xbee_spi.h"
#include "bt_gamepad.h"
#include "config_file.h"
#include "debug_file_logger.h"
#include "monitor_buf.h"
#include <esp_heap_caps.h>
#include <new>

// Hardware globals defined in src/globals.cpp.
// ServoDispatch& avoids including ServoDispatchDirect.h here, which would
// pull in ServoDispatchPrivate.h and duplicate ISR definitions.
extern ServoDispatch& servoDispatch;

// ---------------------------------------------------------------------------
// Reassignable dome/drive serial ports (issue #147) -- see
// include/serial_assignment.h for the port-conflict validation this relies
// on. Only Serial1 and Serial2/AUX_SERIAL are ever reassignable; Serial0
// (WCB/body-controller out) is fixed and handled separately below.
// ---------------------------------------------------------------------------

static HardwareSerial& resolveSerialPort(SerialPortId id) {
  return (id == SerialPortId::kSerial2) ? AUX_SERIAL : Serial1;
}

// Explicit pins required for both ports: ESP32-S3 UART1/UART2 have no
// hardware-fixed default pins and won't route to the right GPIOs without
// them (see pin_config.h's SERIAL1_*_PIN/AUX_SERIAL_*_PIN).
static void beginSerialPort(SerialPortId id, uint32_t baud) {
  if (id == SerialPortId::kSerial2) {
    AUX_SERIAL.begin(baud, SERIAL_8N1, AUX_SERIAL_RX_PIN, AUX_SERIAL_TX_PIN);
  } else {
    Serial1.begin(baud, SERIAL_8N1, SERIAL1_RX_PIN, SERIAL1_TX_PIN);
  }
}

// AmidalaParameters is dominated by Str[MAX_SERIAL_STRINGS] (~67KB, see
// params.h) -- as a plain member it would sit in internal SRAM for the
// life of the process. Heap-allocate it from PSRAM instead: both supported
// boards have PSRAM to spare and internal SRAM does not (issue #172).
// heap_caps_malloc doesn't zero the block the way static BSS storage would,
// so memset before placement-new runs (AmidalaParameters::init(), called
// via getRadioChannelCount() below, also memsets on first use -- this just
// covers the window before that first call).
static AmidalaParameters& allocParamsInPSRAM() {
  void* mem = heap_caps_malloc(sizeof(AmidalaParameters), MALLOC_CAP_SPIRAM);
  memset(mem, 0, sizeof(AmidalaParameters));
  return *new (mem) AmidalaParameters();
}

AmidalaController::AmidalaController()
    : fConsole(),
      fHCR(&SERIAL, HCR_BAUD_RATE),
#ifdef VMUSIC_SERIAL
      fVMusic(VMUSIC_SERIAL),
#endif
      fDriveStick(this), fDomeStick(this),
      fSnipsRight(this, SnipsRemote::kRight), fSnipsLeft(this, SnipsRemote::kLeft),
      params(allocParamsInPSRAM()),
#ifdef RDH_SERIAL
      fAutoDome(RDH_SERIAL),
#endif
      fPPMDecoder(PPMIN_PIN, params.getRadioChannelCount()) {
  // fTankDrive/fDomeDrive are NOT constructed here (issue #147) -- see their
  // declaration in controller.h and the "new" calls in setup() below. This
  // constructor runs at C++ global static-init time (AmidalaController is a
  // global -- see AmidalaFirmware.ino), before params is loaded from flash,
  // so nothing here can depend on a config-driven serial port choice yet.
}

void AmidalaController::emergencyStop() {
#ifdef DRIVE_SYSTEM
  fTankDrive->stop();
  fTankDrive->setEnable(false);
  // Force neutral PWM signals as a safety backup
  servoDispatch.moveTo(1, 0.5); // Drive Left
  servoDispatch.moveTo(0, 0.5); // Drive Right
  // If using serial, the Roboteq script handles its own RWD 100 watchdog
#endif
}

void AmidalaController::domeEmergencyStop() {
#ifdef DOME_DRIVE
  fDomeDrive->stop();
  fDomeDrive->setEnable(false);
#if DOME_DRIVE != DOME_DRIVE_ROBOCLAW
  // Force neutral PWM signal as a safety backup (PWM/Sabertooth only).
  servoDispatch.moveTo(3, 0.5); // Dome
#endif
#endif
}

#ifdef HALL_SENSOR_TEST
// Boot-time wiring check for the dome hall sensor (see include/debug.h).
// Never returns. Runs from setup() once config.txt is loaded and validated so
// it watches the pin the user actually assigned Hall to on the Pins page, not
// the compiled-in default (DOME_HALL_PIN), which would look dead -- with a
// perfectly good sensor -- after the sensor has been moved to another header.
static void runHallSensorTest(const PinRoleType roles[11]) {
  bool assigned = nthPinWithRole(roles, PinRoleType::kHall, 0) != kNoPin;
  uint8_t pin = hallPinOrFallback(roles, DOME_HALL_PIN);
  pinMode(pin, INPUT_PULLUP);
  CONSOLE_SERIAL.print("Hall sensor test — ");
  if (assigned) {
    CONSOLE_SERIAL.print("GPIO ");
    CONSOLE_SERIAL.print(pin);
    CONSOLE_SERIAL.println(" (the pin assigned Hall Sensor; move magnet past sensor)");
  } else {
    CONSOLE_SERIAL.print("no pin is assigned Hall Sensor, watching the default GPIO ");
    CONSOLE_SERIAL.print(pin);
    CONSOLE_SERIAL.println(" (move magnet past sensor)");
  }
  for (int lastState = -1;;) {
    int state = digitalRead(pin);
    if (state != lastState) {
      CONSOLE_SERIAL.println(state == LOW ? "LOW  <- triggered" : "HIGH <- idle");
      lastState = state;
    }
  }
}
#endif

void AmidalaController::setup() {
  fConsole.println(F("Loading config from EEPROM"));
  params.init();

  fConsole.init(this);
  fConfig.init(this);
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

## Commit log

2026-06-14 Get ESP32-S3 port fully functional on hardware
    - Explicit GPIO pins for Serial0 (43/44) and Serial1 (17/18): ESP32-S3
    UART1 has no hardware-fixed pins and silently routes to wrong GPIOs
    without explicit args — this was preventing RoboClaw communication
    - Fix EEPROM on ESP32: add EEPROM.begin(1024) at boot and EEPROM.commit()
    after all writes; without these, calibration and config never persisted
    - Add XBee 3 SPI receive path (xbee_spi.h/cpp): parses ZigBee IO Sample
    frames (0x92) and feeds analog/digital data into pocket remote structs,
    replacing the old andrewrapp UART path
    - Cap xbeeSPIReceiveAll() loop: ATTN pin stuck LOW blocked the animate
    loop indefinitely, preventing Rob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
    [AmidalaFirmware.ino, config.cpp, controller.cpp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]
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2026-06-19 refactor: consolidate web API to single /api/config endpoint + board info
    - Collapse 6 per-section JSON builders into buildFullConfigJson(); all
    config pages now fetch from GET /api/config instead of per-page URLs
    - Add missing R2 Sounds volume field to Audio config page
    - Remove "Amidala RC" branding; home page subtitle now shows firmware
    version, MCU variant, and board revision
    - Add FIRMWARE_VERSION, BOARD_REV, MCU_VARIANT string defines to
    version.h as single source of truth for firmware identity
    - Update web_dev.py mock to flat _config dict matching new API shape
    - Update tests to match consolidated endpoint and buildFullConfigJson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
    [console.cpp]
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2026-06-24 Fix OTA firmware update using standard Update class + dual-OTA partition layout
    The previous implementation wrote directly to the factory partition using
    esp_partition_write() while executing from it — this is why the update
    page never worked. Switch to the standard Arduino ESP32 approach:
    - New ota_0/ota_1 partition tables (8 MB and 16 MB variants) with an
    otadata slot so the bootloader can alternate between slots.
    - Replace the custom flash-write handler with the Arduino Update class,
    which writes to the inactive OTA slot and sets the boot pointer on
    completion.
    - Add sdkconfig.defaults with CONFIG_BOOTLOADER_APP_ROLLBACK_ENABLE=n to
    prevent the boot-loop that originally motiva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
    [ota_16MB.csv, ota_8MB.csv]
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2026-06-28 feat: serial command categories, favorites, and visibility (separate config blocks)
    Adds per-command metadata (categories, favorites, hidden) stored as separate
    config blocks so sstr= entries remain completely unchanged:
    f=1,3,5 → favorites (1-based sstr indices)
    hidden=2,4 → hidden from Droid Control Sequences tab
    cat=Dome|1,3 → category → sstr index mapping (one line per category)
    Firmware changes:
    - Revert SerialString struct to original {name[32], str[32]} — no embedded fields
    - AmidalaParameters gains sstr_favs[], sstr_hidden[], sstr_cats[] arrays
    - config.cpp: revert sstr= to two-field parse; add f=, hidden=, cat= parsers
    - web_api.h: revert sstr JSON to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
    [config.cpp, params.h]
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2026-06-28 test: add buildFullConfigJson JSON serialization tests for sstr meta fields
    Add 7 new tests that verify sstr_favs, sstr_hidden, and sstr_cats are
    correctly serialized into the /api/config JSON. Also add examples of all
    three new config block types (f=, hidden=, cat=) to example_config.txt.
    [example_config.txt]
2026-07-02 feat: add double-press button layer with configurable timeout
    Buttons can now have a double-press action (DB[]) in addition to
    short-press, long-press, and alt-press. When a double-press action is
    configured for a button, the short-press is held for up to `dbtimeout`
    ms (default 300) waiting for a second tap; if none arrives, the
    single-press fires. Buttons without a double-press action are completely
    unaffected and continue to fire immediately.
    - New DB[9] param array and dbtimeout (0–5000 ms, default 300)
    - noteButtonUp() routes button-up through double-press detection;
    checkDoublePressPending() fires expired single-presses each animate()
    - Config keys: db=N,type,... and dbtimeout=N
    -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
    [example_config.txt]
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2026-07-02 feat: stable ID-based serial string references in button actions
    Replace index-based serial string references (fragile to reorder/delete)
    and the intermediate name-based approach with permanent uint16_t IDs.
    Each SerialString gets a stable `id` assigned at creation; ButtonAction
    stores `uint16_t serialid` (0=none) instead of a 32-byte name. IDs
    never change regardless of array reorder or deletion of other entries.
    Key changes:
    - SerialString gains `uint16_t id`; ButtonAction replaces `serialname[32]`
    with `uint16_t serialid` saving ~29 bytes × 40 action slots ≈ 1.16 KB
    - AmidalaParameters gains `nextSstrId` monotonic counter (max(all IDs)+1 on boot)
    - Config format: `sstr=ID|Name|cmd`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
    [example_config.txt]
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2026-07-10 feat: make Bluetooth controller support a runtime toggle (#125)
    USE_BT_CONTROLLER was a compile-time flag, undefined anywhere in
    platformio.ini, so nobody could use a BT gamepad without editing build
    flags and reflashing. It also caused a bug where /config/connectivity
    404'd on real hardware since the whole page route was nested in the
    same #ifdef.
    Replace it with params.btcontrolleron, a runtime setting toggled from
    the connectivity page and applied immediately (no reboot): enabling
    calls BLEDevice::init() (now idempotent), disabling stops any
    scan/connect attempt and forces isConnected() false via the inherited
    onDisconnect() hook — necessary because JoystickController::isConnected()
    is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
    [config.cpp, controller.cpp, params.h]
2026-07-12 feat: document missing config keys and self-heal config.txt on boot (#127)
    example_config.txt was missing ~20 real, parseable config.txt keys,
    including WiFi AP and Bluetooth controller settings entirely (both
    whole-section features with no documented config.txt entry point).
    Added all of them with defaults matching AmidalaParameters::init(),
    in the appropriate existing sections. Also documented (without adding
    default lines) the repeatable/list-style keys that had no mention at
    all: sb= (sound banks), db= (digital-output button mappings), and
    hidden= (hide a serial string from Droid Control).
    Found in passing: domespmin=/domespmax= config.txt parsing is commented
    out in processConfig() (wi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
    [example_config.txt]
2026-07-12 fix: pin espressif32 platform version and add missing BTGamepad includes (#126)
    * fix: pin espressif32 platform version and add missing BTGamepad includes
    pio run was failing: platformio.ini pinned no version for the espressif32
    platform, so it shared one unversioned cache slot across every ESP32
    project on this machine. Working in another repo replaced that slot with
    a pioarduino build (arduino-esp32 3.3.9 / IDF5), which drops the legacy
    RMT API and ESP32-S3 classic-BT headers that Reeltwo's bundled
    PWMDecoder/PSController sources need (Reeltwo compiles its whole src/
    tree once it's a dependency, regardless of what Amidala actually uses).
    Pin to espressif32@7.0.1, the toolchain generation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
    [AmidalaFirmware.ino, i2c_utils.h, params.h]
2026-07-14 Add Firmware Installer wizard with CI-built binary matrix (#128)
    * fix: correct latent DRIVE_SYSTEM/DOME_DRIVE compile-time config bugs
    Bump to 1.1.1. Building a CI matrix across all drive/dome combinations
    (for the upcoming firmware installer wizard) surfaced several bugs that
    were invisible until now, since nobody could easily build an alternate
    combination without hand-editing drive_config.h:
    - controller.h compared DOME_DRIVE against DRIVE_SYSTEM_SABER instead of
    DRIVE_SYSTEM, so TankDriveSabertooth.h was only ever included when the
    dome (not the drive) was Sabertooth.
    - drive_config.h's DRIVE_SYSTEM_SABER branch unconditionally defined
    DOME_DRIVE_SERIAL as a side effect, which l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
    [controller.cpp, controller.h, drive_config.h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]
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2026-07-17 fix: make Autocorrect Gestures actually affect gesture matching (#137)
    params.autocorrect was fully wired into config storage, the API, and
    the General settings UI, but nothing ever read it — Gesture::matches()
    always required an exact, full-length character match. Since a
    recorded gesture gets a '5' appended every time the stick passes back
    through center between direction changes, a human performing a real
    gesture will very often produce a string with a stray or missing '5'
    compared to what was configured, and the toggle meant to compensate
    for that did nothing — explaining reports of gestures never firing
    even with the sequence apparently done correctly (issue #132).
    matches() now ta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
    [buttons.cpp]
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2026-07-25 fix: resume dome random mode after a connection-loss safety stop (#144)
    * fix: resume dome random mode after a connection-loss safety stop
    DomeDriveRoboClaw::stop() unconditionally collapses kStateRandom back to
    kStateHomed whenever it's called. domeEmergencyStop() -> stop() fires on
    any XBee connection lag over 500ms (DomeController::notify()'s safety
    stop), so any connection blip permanently cancelled random mode -- nothing
    ever resumed it once the connection recovered, since enableDomeController()
    only re-enables motor output, not the auto-mode.
    Adds DomeDriveRoboClaw::noteConnectionLossStop()/resumeIfInterrupted() to
    remember and restore random mode specifically around the connection-l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
    [controller.cpp, dome_drive_roboclaw.h]
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2026-07-26 feat: reassignable GPIO pin roles with dynamic per-role counts (#133) (#146)
    Each of the 11 pins already broken out on the board's headers now picks a
    role type (Dout/Analog/PPM/Servo/Hall) instead of a fixed named slot, so
    the count in each category is derived from however many pins currently
    have it -- e.g. trading a digital output for a 5th servo channel actually
    shows 5 servos on the Servos page and one fewer row on Droid Status.
    - include/pin_assignment.h: pure, natively-testable validation module
    (role/pin electrical compatibility, hardware ceilings -- Servo <= 8 the
    ESP32-S3 LEDC limit, PPM/Hall <= 1 -- and the pin<N>role= string scheme).
    - params.h: pinRole[11] replaces the 11 n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
    [AmidalaFirmware.ino, config.cpp, controller.cpp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]
2026-07-26 fix: compensate for processing delay when registering dome home (#142)
    * fix: compensate for processing delay when registering dome home
    processHallTrigger() could only sample the encoder when the main loop got
    around to it, not at the hall sensor's true trigger instant -- reading the
    encoder requires a blocking RoboClaw UART round-trip, which can't safely
    happen inside the ISR. Since the single-threaded main loop also serves
    WiFi requests, SD writes, etc., that gap could be well past one animate()
    tick if something else stalled it. If the dome was moving at the time, the
    registered home ended up rotated by however far it travelled during the
    delay, occasionally producing a large, discrete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
    [dome_drive_roboclaw.cpp, dome_drive_roboclaw.h, dome_position_math.h]
2026-07-26 refactor: defer fTankDrive/fDomeDrive construction to setup() (issue #147) (#150)
    Converts AmidalaController's fTankDrive/fDomeDrive from value members
    bound to a fixed HardwareSerial& at C++ static-init time (before config
    loads) into pointer members constructed inside setup(), once params is
    available. This is prep work for making the dome/drive serial port
    reassignable at runtime, which needs the port choice to come from a
    config value that doesn't exist yet when AmidalaController's own
    constructor runs.
    Incidentally fixes AUX_SERIAL/Serial2 being opened on the wrong pins
    (GPIO43/44, Serial0's pins) for Sabertooth/Roboteq-serial drive builds:
    neither TankDriveRoboteq, TankDriveSabertooth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
    [AmidalaFirmware.ino, config.cpp, controller.cpp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]
2026-07-26 feat: reassignable dome/drive serial ports (#147) (#153)
    Lets a user reassign, via a new Serial Ports config page, which physical
    UART (Serial1 or Serial2/AUX_SERIAL) the dome drive and drive system's
    serial link each use — e.g. move the RoboClaw dome link off Serial2 onto
    Serial1 to free up the other port for different hardware. Defaults
    reproduce today's wiring exactly. Serial0 (WCB/body-controller main-out)
    stays fixed — it already has its own destination toggle — and I2C/true
    software serial remain explicitly out of scope (this board's third port,
    AUX_SERIAL, is confirmed to be genuine hardware UART2 via the ESP32-S3's
    GPIO matrix, not something needing a SoftwareSerial conversion)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
    [config.cpp, controller.cpp, params.h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]
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2026-07-26 Fix serial header numbering to match PCB silkscreen (no offset) (#159)
    * fix: correct serial header numbering to match PCB silkscreen (no offset)
    The Serial Ports page (#153, released in v1.2.0) and monitor.html
    labeled the two reassignable ports "Serial 2"/"Serial 3", based on a
    mistaken assumption that the silkscreen numbering was offset by one
    from the firmware's Serial1/Serial2 names. Confirmed with the board
    designer: the silkscreen actually reads "Serial 0"/"Serial 1"/"Serial
    2" with NO offset -- matching firmware/config.txt naming directly.
    Corrected all three UI labels (serial-ports.html, monitor.html,
    general.html's auxserial3 toggle) to "Serial 1 (GPIO17/18)" / "Serial 2
    (GPIO21/3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
    [example_config.txt]
2026-07-31 fix: guard dome-drive live-apply calls in processConfig() against null fDomeDrive (#160)
    AmidalaController::setup() loads config.txt (loadConfig(), which parses
    every line through AmidalaConfig::processConfig()) before fDomeDrive is
    constructed -- construction is deliberately deferred until after config
    load so it can use config-derived values (serial port, RoboClaw address,
    etc). But processConfig()'s domeflip=, domespeed=, domercaddr=,
    domercchan=, domercqpps=, domefront=, domestall=, and the position-param
    group (via applyDomePositionParams()) all unconditionally dereference
    fDomeDrive to apply the value live -- added across a few PRs to make
    these settings take effect without a reboot.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
    [config.cpp]
2026-08-01 fix: keep dome random mode running through remote disconnects (#162) (#165)
    DomeController::notify()'s lag-based safety stop and onDisconnect()'s
    failsafe-timeout handler both called domeEmergencyStop() unconditionally
    whenever the dome-stick remote's signal dropped -- even when random mode
    was driving the dome autonomously and never reading the joystick at all.
    That defeated the point of the mode: turning it on and walking away
    stopped the dome within 500ms instead of leaving it wandering.
    Guard both connection-loss paths (RoboClaw-only, matching the existing
    DOME_DRIVE_ROBOCLAW pattern) so they skip the stop entirely while random
    mode is active. Deliberate e-stops (web /api/estop, OTA upl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
    [controller.cpp, dome_drive_roboclaw.h]
2026-08-01 feat: log RoboClaw stalls and controller-reported errors to the monitor (#166)
    The dome motor stopping unexpectedly and not restarting has been hard to
    diagnose after the fact -- our own software stall detection
    (checkObstruction()) only ever logged via DEBUG_PRINTLN, which is
    compiled out entirely unless USE_DEBUG is uncommented and a serial cable
    is attached live. And there was no visibility at all into the RoboClaw
    controller's own reported fault/warning bits (driver fault, over
    current, E-Stop input, etc.), which checkObstruction() can't see since
    it only watches encoder movement, and only while homed.
    - Added dome_format_roboclaw_error() (dome_position_math.h) -- a pure,
    unit-tested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
    [dome_drive_roboclaw.cpp, dome_drive_roboclaw.h, dome_position_math.h]
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2026-08-01 fix: correct RoboClaw error bit table against the official manual (#169)
    #166's dome_format_roboclaw_error() decode table was reconstructed from
    memory and had real gaps/mistakes, confirmed once real field data started
    coming back through it:
    - 0x00000008 was labeled MBATT_HIGH_ERR -- that bit doesn't exist.
    Basicmicro's table jumps from 0x4 straight to 0x10; there's no error
    defined at 0x8.
    - Missing entirely: M1/M2 Speed Error (0x100/0x200), M1/M2 Position
    Error (0x400/0x800), Main/Logic Battery Low/High Warning, Temperature
    Warning x2, S4/S5 Limit Switch, M1/M2 Idle Warning, Reset Warning, and
    M1/M2 Over Regen Warning (0x1000000-0x80000000) -- exactly the range
    that showed up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
    [dome_position_math.h]
2026-08-01 feat: gate RoboClaw error/warning logging behind a config toggle, off by default (#170)
    Most users don't need to see checkRoboClawStatus()'s "RoboClaw error
    0x... [...]" monitor lines unless they're actively debugging a dome
    issue -- added a new domeerrlog= config setting (default off) so the
    poll is skipped entirely (not just the logging) while disabled, with
    zero ongoing serial-bus cost.
    - DomeDriveRoboClaw::setErrorLogging()/getErrorLogging() gate
    checkRoboClawStatus()'s whole body.
    - Wired through config.txt (domeerrlog=y/n, live-applies to the running
    drive like domercaddr=/domercchan=/domestall=), boot-time setup(),
    ensureConfigDefaults() (self-heals into existing users' config.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
    [config.cpp, controller.cpp, dome_drive_roboclaw.cpp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]
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2026-08-01 refactor: turn processConfig() into a dispatch table over small handlers (#171) (#175)
    AmidalaConfig::processConfig() was one large if/else-if chain matching
    every config.txt key. It grew large enough on the ESP32-S3/Xtensa
    toolchain to trip a link-time "windowed longcall crosses 1GB boundary"
    error -- a hard limit on a single function's compiled body size (#170
    split dome/RoboClaw keys into processDomeConfig() as a stopgap, but
    that only bought headroom once; nothing stopped either function from
    tripping the same limit again as more settings get added).
    Splits every key (~110 of them, including processDomeConfig()'s, which
    is retired as a separate concept) into its own small handler functi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
    [config.cpp]
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2026-08-02 fix: gesture end press swallowed by idle-timeout race, make gesture timeout a runtime setting (#177)
    Field report: gestures felt like they needed a long wait before the next
    one would register. Root cause in DomeController::process()
    (src/drive_controllers.cpp): while collecting a gesture, the idle-timeout
    check ran before the "did L3 just get released" check. An end press
    landing on the same animate() cycle the deadline had already passed (a
    careful multi-stroke gesture, or just a pause before the final click)
    fell into the timeout branch instead, which never looks at
    event.button_up.l3 -- the gesture was silently discarded and the click
    meant to end it did nothing. Reordered so a real L3 r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
    [config.cpp, params.h]
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2026-08-27 fix: harden XBee receive path against dropped packets and connect flicker (#185) (#186)
    Three independent gaps found while investigating dropped button presses
    and flickering online/offline status on the pocket remotes:
    - params.fst (failsafe timeout) had no software default, unlike every
    sibling setting -- a board without the legacy EEPROM "SC23" block fell
    through to 0, making the failsafe check in animate() true on almost
    every loop pass between real packets.
    - XBEE_ATTN_PIN never got a pinMode() call, and the schematic confirms no
    hardware pull-up exists on that open-drain line either.
    - xbeeReadFrame() discarded the XBee API checksum byte without verifying
    it, and the drain l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
    [AmidalaFirmware.ino, params.h]
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2026-08-28 harden: clamp legacy SC23 EEPROM block fields to valid ranges on load (#189)
    The "SC23" magic header only proves this block was intentionally
    written at some point -- it says nothing about whether every byte in
    it is still what was written. A restart landing mid-EEPROM-commit (or
    any other partial write) can corrupt the data after an intact
    signature, and until now those raw bytes went straight into live
    params with zero validation.
    Clamps rcchn/minpulse/maxpulse/rvrmin/rvlmin/rvrmax/rvlmax/fst to the
    same bounds their own cfg_*() setters in config.cpp already enforce
    for a live edit, so a corrupted-but-signature-matched block can't hand
    a running remote's failsafe timeout or a servo's puls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
    [params.h]
2026-08-28 fix: add XBee3 settle delay to setup() to avoid cold-boot connect race (#190)
    Field reports (#185): pocket remotes sometimes never connect on true
    cold power-on, but any reset that doesn't remove power from the XBee
    (web UI or the board's physical reset button) fixes it immediately.
    The XBee3's ~RESET pin has no GPIO driving it -- only a passive R1/C1
    RC network (10k/100nF per the PCB schematic), giving a ~1.2ms release
    delay. setup() reaches SPI.begin() and starts driving XBEE_CS_PIN well
    within that same order of magnitude, so on a cold power-on both chips
    can be racing out of reset together, with the ESP32 starting SPI
    traffic before the XBee3's own oscillator/boot sequence -- which need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
    [AmidalaFirmware.ino]
2026-08-28 Revert "fix: harden XBee receive path against dropped packets and connect flicker (#185) (#186)" (#192)
    This reverts commit 4d1b052641edaf108c43681889e540407dec77f4.
    [AmidalaFirmware.ino, params.h]
2026-08-28 fix: restore #186's checksum/fst-default fixes minus the ATTN pinMode line (#193)
    #186 (reverted in #192) bundled three independent changes together:
    checksum validation on received XBee frames, a default for params.fst,
    and pinMode(XBEE_ATTN_PIN, INPUT_PULLUP). A field report of pocket
    remotes intermittently never connecting on cold power-on -- fixed only
    by a reset that didn't touch XBee power, never by waiting longer --
    led to a clean A/B test on hardware: with everything from #186 present
    except the pinMode line, cold boot connects reliably every time.
    Root cause isn't fully understood (possibly the pull-up interacting
    with a bootstrap/config sampling window on the XBee3's own DIO1/AD1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
    [AmidalaFirmware.ino, params.h]
2026-08-28 feat: tee USE_DEBUG output into the web serial monitor (#194)
    DEBUG_PRINT/DEBUG_PRINTLN/etc. (ReelTwo's macros, gated by debug.h's
    USE_DEBUG et al) have always gone straight to the physical USB serial
    port only -- unlike AmidalaConsole's output, which console.cpp already
    tees into the web Monitor page's ring buffer via monAppend(). That gap
    was a real pain point diagnosing issue #185's cold-boot XBee report:
    Robert needed a laptop physically plugged in to capture a debug log at
    all, when the point of the web Monitor page is to not need that.
    Adds include/debug_monitor_tee.h: a Print-derived class that duplicates
    every DEBUG_PRINT-family call to both the real serial port (unchanged
    behavior)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
    [controller.h, dome_drive_roboclaw.cpp]
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
